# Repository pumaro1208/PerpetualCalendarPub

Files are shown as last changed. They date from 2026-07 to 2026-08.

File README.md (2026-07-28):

# v1.6 PATCH — architecture A' (cam-gated slider strikers + E1 receivers)
Authorized by Ron 2026-07-09. Sim b40 is the functional spec of record.

## Parts (print all in PLA Matte Charcoal — rotating)
- 30_drive_v16 — drive wheel re-head: body + long tooth + hub/crank + THREE
  radial slider channels at 15/30/45 deg (rails z4.0-8.0, lips 7.1-8.0,
  floor pads 4.0-5.2, detent bumps at both seats). Witness dot = 23h channel.
- 31_sliders_v16 — three sliders on one plate. ID dots: 3=23h, 2=22h, 1=21h.
  DISTINCT NOSE LENGTHS: each slider reaches only its own cam track —
  cross-assembly is physically impossible. Strike pin r1.6, band 5.2-8.0.
- 32_camring_v16 — board-top ring (z 4.05-4.75, OD 41.6): three blind groove
  tracks at world r 34.6/37.4/40.2 (23h/22h/21h), lobes (1.6 mm inward) at
  board positions 30/29/28, dwell 1.35 pitch, cosine ramps. Witness dot =
  pos-1 at the OD. Mount: seat on board top, clock the dot to the mesh line
  with the board at Jan 1 (pos 1); thin CA at three points. Registration
  tolerance +/-3 deg (harness G4) — witness clocking suffices.
- 33_receiver_month_v16 — month satellite lamina: mesh profile + spacer hub +
  FIVE E1 involute strike teeth (patent claim 5 form) at 30-deg stations,
  base 6 deg. Witness dot marks station k=0.
- 34_receiver_feb_v16 — single-tooth E1 lamina, same construction.
- 35_leap_shuttle_v16 — the v1.5 leap shuttle re-headed with the E1 tooth;
  the Geneva year key is unchanged (follower pin preserved).

## The cam law (normative, sim-derived)
Striker extended ONLY on its strike evening. Lobe map (400-yr engine sweep):
21h->pos 28, 22h->pos 29, 23h->pos 30 — one lobe per track; the cascade
itself walks the board through the positions, arming each striker in turn.
Stroke 1.6 mm; retracted adjacency clearance 2.54 mm emitted (harness 1.23).

## Acceptance (all 19 gates PASS; all 6 parts watertight, 0 open edges)
Fit: channel gap 5.4 / slider 5.0; lip retention 0.5/side; peg d2.4 in
groove 2.7 (0.35 mm wall engagement). Register: extended pin = FINGER_R
30.70 exact, peg valley/lobe = track radii exact, lobes verified at the pos
lattice and flat elsewhere. Keep-outs: ring OD 41.6 vs pin sweep 42.8;
nose-over-ring 0.45 mm; strike bands identical by construction (5.2-8.0).
Harness lineage: stroke, E1 profile, and station base are the EXACT
parameters judged in arch_a_prime.py (G1 1.13P/1.33P bidirectional, G2
silent, G3 1.23 mm, G4 +/-3 deg) — the emitted parts and the judged
mechanism share one parameter set.

## Bench items on first assembly (Stage 1.5)
1. Slider slide-fit after printing (scrape lips if needed; PTFE dry lube).
2. Detent click at both seats; peg engagement depth 0.35 (verify no lift-out).
3. The characterized 23:15 tight passage: midnight finger entry clearance
   against the mid-push board (from the sim's grind log).
4. Reverse un-skips: park -> pickup -> push, per sim b40.

## Receiver clocking table (harness-judged, 2026-07-09)
Each lamina's witness dot clocks to its satellite per this table. The base
window is the selectivity margin; center it.
| train | satellite | station (carrier) | judged base | passing window |
|---|---|---|---|---|
| month 23h| 210 | STN_M (reference) | 180.0 deg | (session 3) |
| feb 22h  | 211 | STN_M + 1 pitch | 315.0 deg | 310.0-320.0 |
| leap 21h | 212 | STN_M + 2 pitches | 335.0 deg | 327.5-340.0 |
The station offsets are the natural carrier positions of satellites 211/212
(one and two cascade steps ahead of 210) — the harness confirms the
assignment; no new posts required.

## Part 36 — friction-set hour ring (roadmap tier 1, added 2026-07-19)
Press-fit indicator ring on the drive hub: three printed flex fingers grip
the hub column at 0.15 mm interference each (the cannon-pinion principle,
in PLA); the pointer flag reads the displayed hour. USE: after any fast
catch-up cranking (the drawer scenario), twist the ring by hand to restore
the true hour — date advanced, displayed time preserved, the outcome of
the UN-32's date position with one part and zero mechanism. Rides z
8.6-11.6, 0.6 mm above the channel tops; only the fingers touch the hub.
BENCH: verify twist friction is firm but hand-turnable; if too tight,
scrape one finger; if loose, a strip of tape on the hub shims it.
STAGE-C NOTE: the true date-ONLY drive (hands stationary while the
calendar advances) is the keyless-works dog clutch — deliberately deferred
to the watch stage per ROADMAP-clock-watch.md.

# FLAG-FREE DETENT SET (findings 97–99 + coupling redesign, 2026-07-28)
The machine's sole index. The daily drive advances the board; this detent settles
it onto each day's position and holds it. Reversibility is preserved (flexure, not
ratchet). All parts PLA (rotating parts black), print FLAT, no supports.
Regenerate the whole set with `parts/emit_final.py`; gate is `qc_sweep_central.py`.

## Parts
- 02e_board_bigbore — the v1.3 program board (31 involute rim teeth, tip 41.86;
  31 day-tick bumps at r33.5 with the tall pos-1 witness; month satellite post +
  D-key), UNCHANGED except the central bore opened 8.7 → 10.9 mm to take the star's
  press-tube. Prints teeth-up, flat on the bed. THE ONE PART RE-PRINTED from the
  bench (bigger bore is the only change).
- 50d_star_hub — detent star, flag-free. 31 symmetric shallow-triangle notches
  (root 26, tip 28.5 → 2.5 mm deep) on a scallop disc, plus an integral CENTRAL
  press-tube (ID rides the program post, OD press-fits the board bore) that couples
  the star rigidly and concentrically to the board — no outrigger, no drop-in pin.
  Prints scallop-down, tube rising. Rides the post; board seats on the disc top;
  the disc spins on the fixture thrust pad.
- 49_fixture_r58 — basin bench fixture: program + drive posts (square-key sun seat),
  drive collar, a central THRUST PAD the star disc spins on (replaces the program
  collar), and the two bridge-jumper anchor pins at r30.5. Wedge station = 270°.
- 51_bridge_arm — the bridge jumper (finding #99). A pinned-pinned flexure (span 35
  between the boss inner edges; both pin bores OPEN top-to-bottom, finding 64/93),
  1.05 mm wide, carrying a POINTED wedge at mid-span: a sharp apex reaching r27.0
  (clear jump into each notch) with wide shoulders that bear on BOTH tooth flanks
  (geometry centers it). Loaded identically forward and reverse. Beam pulled in to
  r30.5 so the riser is short (~2.2 mm) — the sideways tooth force has little lever
  arm to twist the wedge. k = 0.62 N/mm; peak 23 MPa (2.2× PLA) at the 1.5 mm stroke.

## Design laws honored
Reversibility — pinned-pinned flexure is symmetric fwd/rev, positive transfer, no
ratchet. Full-depth notch + short pointed wedge = a positive index with a light,
clean jump. Both press fits are interference — no glue. The gate in the repo
(qc_sweep_central.py) is the gate that cleared this plate (finding 96 doctrine).

## Bench items on first assembly
1. Star central tube → board bore: designed interference press; tune on first fit.
2. Bridge pins → anchor bores: interference; bores print open top-to-bottom.
3. Wedge drops into each notch with a clear click and self-centers on both flanks;
   verify no twist as the board sweeps its 31 positions.
4. Star disc spins freely on the thrust pad; board seats flat on the disc top.

## Board 02f — pegless/dotless (engine clearance sweep, 2026-07-28)
02f = 02e with the 31 perimeter day-tick pegs (r33.5) AND the three station witness
dots (r35.05) REMOVED. The engine interference sweep (parts/engine_sweep.py, disc-
about-fixed-pivot model, frame self-checked against the sun↔month mesh) found that
on 02e the tall day-1 peg (+0.8mm) and station dots M/F (+0.2mm) poke up into the
MONTH satellite's mesh lamina (underside z10.4) even with the finding-63 spacer —
the 30 short pegs clear by 0.4mm, but those three do not. 02f leaves zero raised
obstacles on the board face except the intended satellite pivot post; the sweep
reports CLEAR. Involute rim, 10.9 press-bore, and the month post + D-key are
UNCHANGED, so the flag-free detent press-fit (star tube -> board bore) is unaffected.
Sun tower confirmed correctly configured (spans LA/LB/LC, meshes at altitude).
02f SUPERSEDES 02e for the reprint. See docs/engine-clearance-sweep.md.

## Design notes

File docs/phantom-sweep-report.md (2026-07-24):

# Phantom-Pass Sweep — Report (2026-07-08)

Push-classified watershed verification on the real profiles, full year of
board parks. The gating metric is TOOTH-PUSH, not contact: grazes are design
behavior if push < 0.35 pitch (crest 0.5); un-gated ADVANCE is failure.
Tooling: phantom_sweep2.py (+ phantom_sweep.py first pass).

## P1 — PASS: month gating works; watershed confirmed on real geometry
Over a full year the 23h tooth vs the 5-tooth month lamina (OFF=9.75)
produces engagement ONLY at the strike passes; all other passes are clean or
graze with worst push 0.042 pitch — an order of magnitude under the crest.
Zero danger-band events. The paired same-pass "strikes" (az -6 @ 1.04P and
az +6 @ 0.75P) are an enumeration artifact: a skip evening advances the board
TWICE (skip + midnight), so the running machine visits only ONE evening of
each pair — WHICH one is selected by assembly date-clocking. Note the az -6
evening's push is 1.04 pitch = TOOTH-COMPLETED (see S4 note below).

## P2 — OPEN: feb single-tooth fires twice a year in the raw scan
The feb tooth's presentation phase advances 210 deg per monthly pass, cycling
all twelve 30-deg phases annually; the raw scan shows 2 crest-crossing
engagements/yr (0.98P and 0.73P on different passes). Whether the running
machine actually VISITS both depends on the skip-inclusive kinematic
sequence and the chosen engagement parity — the same subtlety as P1's pairs,
but across passes. Needs the sequence-aware sweep (enumerate the true
calendar sequence of parks, not all parks) before declaring pass/fail.
Leap shares the single-tooth phase-cycle exposure; same follow-up.

## P3 — leap slider: one critical margin, one healthy spec
ARMED: push 0.507 pitch — 0.007 pitch (0.08 deg) past the crest. RAZOR-THIN:
FDM noise flips it and leap years silently fail to skip. This is the
sharpest margin in the machine and needs geometry attention in the S4/leap
session (deeper armed reach or wider tooth land).
RETRACTED clearance vs cam travel: 1.0 mm -> 0.060 mm (too thin);
1.2 -> 0.255; 1.6 -> 0.654 (the v1.5 follower stroke: HEALTHY, PASS);
2.0 -> 1.052. Minimum viable travel ~1.15 mm; the 1.6 mm design has ~4x
margin. The retracted-gating half of the leap watershed is confirmed.

## S4 note — resolution path upgraded
P1 found an evening whose month-skip push is 1.04 pitch: the tooth itself
completes the pitch, satisfying the bidirectionality rule from the strike
sweep. If that (evening, clocking) combination also reverses — plausible,
untested due to a board-angle/satellite-spin aliasing my quick probes hit —
then S4 is resolved by ASSEMBLY CLOCKING alone, no geometry change: the
date-clocking must place skips on the az -6 evenings and the satellite OFF
must match. The S4 design session should START with this sequence-aware
clocking search before considering the twin-flank receiver.

## Standing next steps
1. Sequence-aware sweep (calendar-true park sequence): settles P2's feb
   double-fire and executes the S4 clocking search at the exact strike
   angles. Highest priority; reuses all of this tooling.
2. Leap armed-margin geometry (with S4 session).
3. Sun-mesh orbit sweep (7t pinion undercut, continuous mesh) thereafter.

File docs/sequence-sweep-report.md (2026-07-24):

# Sequence-Aware Sweep — Report (2026-07-08)

Walks the engine's TRUE calendar sequence of board parks (skips included) and
evaluates every 23h/22h drive-tooth pass at the exact board angle and
satellite spin the machine will occupy. Tooling: sequence_sweep.py; the
calendar walker + per-pass push classification are the standing acceptance
harness for the skip-transfer redesign.

## Headline: NO clocking window exists for the month or feb laminas
Scanned 61 month clockings and 241 feb clockings against the full
calendar-true year. None produces the required pattern (every logical strike
engages >= 0.5 pitch; every other visited pass gated < 0.35 pitch).

The autopsy at the best candidate clocking (month, OFF = 9.75) shows WHY —
both failure classes coexist:
 - FALSE STRIKES: the eve-of-skip evenings (satellite az -5.8) engage at
   1.042 pitch on several months (n = 121, 214, 276, 338) plus stray az +5.8
   engagements on non-skip months (n = 215, 370). Each is a full extra step:
   the calendar runs FAST.
 - MISSED STRIKES: two of the five logical skip evenings get no engagement
   (n = 184) or a 0.042-pitch graze (n = 339): the calendar runs SLOW.
No clocking trades these off to zero simultaneously. Verdict supersedes the
phantom sweep's all-parks PASS (which averaged over parks the sequence never
visits and missed the visited-sequence correlations).

## Finding S7 — the skip gating as built cannot serve the calendar
The presentation-phase engagement window of the current lamina tooth form is
WIDER than one station on the approach side (hence eve-of-skip false strikes)
while the nominal-side engagement varies 0.75 -> 0.04 -> 0 pitch across
evenings the 30-deg station-lattice theory says are equivalent — the physical
engagement depends on approach geometry in a way the lattice doesn't capture.
(The lattice discrepancy itself is an open analysis item for the session; the
empirical verdict does not depend on resolving it.)

## S4 status: clocking resolution is DEAD; redesign confirmed
The hoped-for fix-by-witness-marks is closed. The skip-transfer design
session is confirmed necessary, now with the full requirement set measured:
 R1 bidirectional: tooth-completed push >= 1.0 pitch both directions
 R2 selective: presentation window narrower than one evening's phase step
    (no eve-of-skip engagement)
 R3 reliable: >= 0.65-pitch push margin at every legitimate strike (the
    leap's current 0.507 shows what 0.007 margin looks like)
 R4 gated: all other visited passes < 0.35-pitch push
The twin-flank slot receiver remains the lead candidate: a slot is engaged
positively in both directions (R1), only when entered (R2), and its
engagement depth is designable (R3). Every candidate gets judged by
sequence_sweep.py before any STL is cut.

## Stage 1 print decision (updated)
Hold: sun tower, all three satellites, leap sliding tooth (the skip train —
S4/S7 redesign scope). Clear to print: everything else in the engine — base,
board, drive wheel, jumper, carriers, caps — the daily drive is fully
verified (S1/S2), and the S3 margins are bench items on exactly these parts.
Printing the cleared set banks bearing/detent/double-step data that feeds
the redesign.

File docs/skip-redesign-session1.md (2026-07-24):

# Skip-Transfer Redesign — Session 1 Findings (2026-07-08)

## Candidate tested: pin-and-slot (drive strike teeth -> pins; lamina teeth
## -> twin-rail slots), judged in the calendar-true sequence harness.

R1 SOLVED by the candidate: strike pushes 1.2-1.6 pitch, tooth-completed,
with reverse engagement available by the same slot geometry — the Geneva
pattern delivers bidirectionality exactly as predicted.

R2 UNSOLVABLE by ANY satellite-borne receiver — the decisive measurement:
the satellite's presentation POINTING phase advances only 6.8 deg per
evening (18.39 deg spin minus 11.61 deg orbit). Any physical receiving
feature at r~18 subtends 10-15 deg, so it inevitably presents across 2-4
consecutive evenings. The sequence autopsy confirms: eve-of-skip false
engagements (1.6-2.3 pitch — worse than the tooth, since a rail drives
harder than a crowned tooth corner) at EVERY clocking, plus one strike
evening served a day early. This also retro-explains S7: the original
crowned tooth was a partial-selectivity compromise that failed both ways.

## The architectural conclusion
Skip gating needs a SECOND key whose phase moves a full station per evening.
The machine already owns one: the BOARD advances 11.61 deg per evening.

PROPOSAL for Session 2 — board-position masking:
A thin MASK lamina riding the board at each strike band (or one ring serving
all three), carrying a single APERTURE at the pos-30 (pos-29/28 for feb/
leap) angular station. The drive pin physically reaches the satellite slot
only THROUGH the aperture: on any other evening the mask blanks the pin at
full board-pitch discrimination (11.6 deg/evening — crisp), while the
satellite slot provides WHICH-month gating exactly as the presence concept
intends. Two keys, two questions: the mask answers "is tonight a skip
night?", the satellite answers "is this a skip month?". Both must say yes.
Design notes: masks ride the board (rotation parity preserved — nested,
no inversion); apertures are passive (no springs, no stored state — state
read at moment of use); pin length/z unchanged; adds 1-3 thin laminae to
the board stack and ~1.5 mm of z per band to thread the pin through.
Leap keeps the v1.5 slider (retract spec verified: 1.6 mm stroke, 0.65 mm
clearance) — the slider now retracts the SLOT, and the armed-margin problem
dissolves because the pin-slot push is 1.2P+, not 0.507P.

## Session 2 agenda
1. Parametrize mask ring + aperture + pin z-threading; extend the harness's
   overlap model with the mask (one more polar profile per band).
2. Judge in the sequence harness: all four R's, forward AND reverse, all
   three satellites, plus mask-edge graze checks (the new phantom class).
3. If green: v1.6 patch — regenerate drive wheel (pins), satellites (slots),
   board (+mask laminae), sun tower (band heights); full pipeline;
   witness-mark spec for satellite clocking.
Stage 1 split unchanged: skip train on hold; the rest of the engine prints.

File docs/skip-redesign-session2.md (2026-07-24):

# Skip-Transfer Redesign — Session 2 (2026-07-08)

## E1 verdict: bidirectional YES, selective NO — adopted as the RECEIVER
## FORM, rejected as the complete architecture.

The patent-literal involute receiver (board-tooth profile, superposition-
registered) measured 1.13P forward / 1.33P reverse, settling exactly +-1.000
pitch — R1 solved, party-trick class, 0.37P crest margin. But the calendar-
true selectivity gate fails at ALL 12 station assignments: the day-after
evening engages at 0.77 pitch (over the 0.5 crest -> false strike). The
6.8 deg/evening pointing crawl defeats every receiver form — wedge, slot,
involute — confirming Session 1's structural conclusion with the best
possible receiver.

## Mask analysis: the naive shield is geometrically impossible
Worked through in this session; recording so it stays dead:
 - Any board-riding shield inside the striker's swept annulus (r 40.7-44.9)
   is TOUCHED BY THE STRIKER on masked evenings; a striker pressing any
   board-borne surface IS a false step. Masking the striker's path is
   self-defeating.
 - A shield inside r 40.7 (striker-safe) instead COLLIDES with the emerged
   rigid receiver (tip 41.86) on masked evenings. Rigid receivers cannot be
   masked without crashing into the mask.
Conclusion: the second key cannot be a passive wall anywhere in the
engagement annulus. It must act on a COMPLIANT receiver.

## The converged architecture — generalize the leap slider
The machine already contains the answer, proven twice over: the patent's
sliding plate 212 (springless, cam-positioned, board-guided) and our own
v1.5 live-read follower/slider for the leap. Proposal:

  ALL THREE skip receivers become SLIDING involute teeth (E1 profile) on
  their satellites, positioned by board-referenced cams — radially OUT
  (engageable) only when both keys agree:
    key 1 (which month): satellite spin aligns the slider's cam follower
      with the cam's admission window — the presence concept, now acting on
      a 1.6 mm radial stroke instead of raw tooth exposure;
    key 2 (which evening): the cam profile is indexed to the BOARD lattice
      (11.6 deg/evening discrimination — the crisp key), so the slider pops
      out only at the strike park and is positively retracted the evening
      before and after.
  Retracted clearance is a solved spec (1.6 mm stroke -> 0.65 mm, phantom
  sweep P3). Engaged, the slider presents the E1 involute tooth -> 1.1-1.3P
  bidirectional push. Springless, no stored state (cam read at moment of
  use), rotation-parity preserved. Cost: two more sliders + cam surfaces —
  the leap train's pattern replicated for month and feb.

## Decision for Ron
 (A) Three-slider architecture above (lead candidate: every element already
     exists somewhere in the machine; z-stack grows by the cam surfaces).
 (B) Embodiment-2-style blocked output (larger architectural change; strongest
     prior art for positive indexing; would touch the daily drive too).
Ron's Fig. 2/3 + Fig. 4-9 read now directly informs A vs B — the sliding
plate's stud guidance (Fig. 3) is the template for A's sliders.
Session 3: parametrize the chosen architecture; judge in the sequence
harness (all three satellites, both directions, mask-edge/cam-edge grazes);
if green -> v1.6 patch.

Stage 1 unchanged: skip train held; the rest of the engine prints.

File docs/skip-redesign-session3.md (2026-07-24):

# Skip-Transfer Redesign — Session 3 VERDICT (2026-07-08)

## Architecture A' — cam-gated SLIDER STRIKERS + rigid E1 receivers: PASSES

The inversion that made it buildable: gate the STRIKERS, not the receivers.
The three skip strike teeth on the 24h wheel become radial sliders (three
sliders total, all on one part), extended only when their peg reads a lobe
on a board-riding cam ring. Strike load is tangential, slider travel is
radial — orthogonal, so drive force cannot back-drive the gate (the leap
slider's own proof). Cam contact is a smooth track — no false-step torque
(the v1.5 follower's own proof). Receivers are rigid involute laminae in
the E1 patent-claim-5 form. Two keys: the board-riding cam answers "is
tonight the skip evening?" at 11.6 deg/evening; the satellite station set
answers "is this a skip month?" at 150 deg/month. Both passive, springless,
read at moment of use.

## Sequence-harness judgment, month train (the decisive case), base 6:
  G1  all 5 skip evenings: forward push >= 1.125 P, reverse >= 1.327 P,
      settled EXACTLY +/-1.000 pitch — BIDIRECTIONAL skips in the
      calendar-true sequence. The party trick, end to end.
  G2  non-skip months' extended evenings: 0.000 P — perfectly silent.
      The 5-consecutive-station set lands the 5 skip months exactly
      (stations walk +5/month, 5 and 12 coprime; verified in-scan).
  G3  adjacent evenings, striker retracted at the leap-proven 1.6 mm
      stroke: minimum clearance 1.23 mm (gate 0.30). At 2.0 mm: 1.60 mm.
      (First run reported -0.13 mm from a sign error in the retraction
      model — the harness extended instead of retracting; fixed, re-run.)
  G4  registration tolerance: passes at least +/-3 deg of satellite
      clocking error — assembly-friendly; witness marks suffice.

## Requirement scorecard (R1-R4 from the strike/phantom/sequence sweeps)
  R1 bidirectional tooth-completed push  ....... PASS (1.13/1.33 P)
  R2 evening selectivity ....................... PASS (cam gate, G2+G3)
  R3 healthy margins ........................... PASS (0.37P crest margin;
                                                  1.23 mm retract clear)
  R4 all other visited passes gated ............ PASS (zero contact)

## Remaining before v1.6 geometry
  1. Feb and leap trains through the same harness (single-station cases,
     geometry class identical; leap keeps the v1.5 follower for the year
     key, its striker gains the 21h slider like the others).
  2. Natural-evening re-clocking note: skips land at pos 27/28/29 with the
     serving satellite at -5.83 deg — display mapping shifts one pitch;
     witness-mark spec at base-6 registration.
  3. v1.6 patch: drive wheel (3 slider strikers + pegs + detent bumps),
     board cam ring (3 lobes/tracks), satellite laminae (E1 involute
     receivers), leap slider re-headed, witness marks. Full pipeline:
     regenerate -> watertight -> acceptance sims -> sequence harness ->
     package. Awaiting Ron's approval of A' and his Fig. 3 read on the
     patent's stud-guidance pattern for the slider details.

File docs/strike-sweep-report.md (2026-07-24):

# Strike-Transit Sweep — Physical Acceptance Report (2026-07-08)

Quasi-static 1-DOF contact simulation of the strike transfers using the ACTUAL
generator profiles (31t stub involute board, 24t-basis stub drive tooth at the
+2.0 mm spread center distance, v1.3 strike lamina with symmetric crown, and
the real v1.2 jumper V-nose geometry, detent-coupled). Tooling:
strike_transit_sweep.py + lamina_bidir scans; results in sweep_results.json.

## S1 — CLEARED: the jumper's inherited clocking is correct
Solved from geometry, no assumptions: the V-nose's deepest seat parks the
board with a tooth VALLEY centered on the mesh line to 0.025 deg. The v1.2
jumper at 12 x PITCH is correctly clocked for the v1.3 drive. Detent snap is
strong (seat-vs-crest depth asymmetry ~270:1). Park-error tolerance window
for a clean transit: -1.0 .. +4.0 deg. The pre-print worry is retired;
the bench check remains (verify the printed park phase lands in-window).

## S2 — PASS: the daily (midnight) transfer is fully bidirectional
Forward: settled advance exactly 1.0011 pitch (solver resolution). Reverse:
exactly 1.0000 pitch back. Measured physical backlash: the board holds
through 24.3 deg of reverse crank (~1.6 h of crank time) before the reverse
push begins — this is the documented expectation for the reverse-cranking
bench test, not a defect. Bidirectionality of the daily drive comes from
MULTI-TOOTH interaction: the drive tooth itself carries the board 1.41
pitches (catching the next board tooth), so the tooth — not the detent —
completes the pitch in both directions.

## S3 — MARGIN FLAGS on the daily transfer (bench-first, geometry-second)
(a) Forward excursion reaches 1.412 pitch: only 1.02 deg (~0.75 mm of flank
position) short of the next detent crest. Past it = DOUBLE-STEP (skips a
day). (b) Nominal entry approach clearance is 0.021 mm — a graze. Both sit
inside typical FDM error. Plan: measure on the Stage 1 print first (count
double-steps over a simulated month of cranking; listen for entry clicks);
if real, the fixes are small (drive-tooth tip relief, +0.3 spread) and cheap
to regenerate. Not a print blocker by itself.

## S4 — DESIGN FLAW: all satellite strikes are FORWARD-ONLY as built
The month lamina's tooth-only push is 0.753 pitch; the JUMPER completes the
remaining 0.247. That completion is irreversible: reversing, the descending
drive tooth arrives to find the lamina a quarter-pitch beyond reach and
passes through empty space. Verified exhaustively: no satellite clocking
(121 scanned, mod 30), at either candidate strike evening (satellite at
-5.83 or +5.78 deg), with lamina reach extended up to +1.3 mm, produces a
reverse-capable transit. The feb and leap laminas share the single-tooth
geometry class: the same result applies to the 22h and 21h strikes.

Consequence: reverse-cranking through any month-end cannot un-do the skip.
The board un-steps daily but the skips stand — the calendar de-syncs. This
violates design law 1 (full bidirectionality), which the simulator's engine
assumes ("reversing: month skip undone" is real in the spec, unimplementable
in the current laminas).

THE RULE THIS EXPOSES (add to the design laws' commentary): a strike
transfer is bidirectional only if the TOOTH ITSELF pushes >= 1.0 pitch; any
completion delegated to the detent is a one-way ratchet in disguise. The
board drive satisfies it via multi-tooth contact; a single-tooth lamina
cannot (single-flank contact arc maxes near 0.75 pitch at this geometry).

Fix directions for the design session (transfer must be PROVEN before
geometry, per project protocol):
  1. Asymmetric lamina tooth: extend the reverse flank so the descending
     tooth catches it despite the detent's completion (~5-7 deg wider on one
     side); requires phantom-pass clearance checks on adjacent evenings.
  2. Twin-flank receiver: two short teeth per station forming a slot the
     drive tooth enters — contact on either flank by direction (Geneva-like,
     positive both ways).
  3. Reduce detent completion authority for skip strikes (deeper conjugate
     engagement via module/center-distance changes at the strike bands).
Option 2 is the one that satisfies the >= 1-pitch-push rule by construction.

## S5 — Satellite assembly clocking
Forward-capable clocking exists in a window around OFF ~ 9-10 deg (mod 30);
the exact witness-mark spec should be issued together with the S4 redesign
(the fix will move it). The clocking failure mode (satellite meshed one
sun-tooth off = 30 deg = silent month-end miss) stands confirmed; witness
marks on all three satellites are required in the next patch regardless.

## S6 — Housekeeping
strike_profile's docstring claims "+theta corner relief"; the code implements
a symmetric crown. Docstring stale; code is the better design. Correct the
comment in the next patch.

## Stage 1 impact
S1/S2 clear the engine's daily drive for print. S3 is bench-first. S4 means
the satellite laminas (sun tower strike bands + leap tooth) as generated are
forward-only: printing Stage 1 now yields a demonstrator whose skips work
forward and cannot be reverse-cranked through month-ends. Options: hold the
sun-tower/leap parts for the S4 session, or print the full Stage 1 as a
forward-alpha to bank assembly/bearing/detent learning while S4 is designed.
Ron's call.

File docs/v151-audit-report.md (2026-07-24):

# v1.5.1 — Audit Pass & Patch Report (2026-07-07)

Full-solids audit of the v1.5 set against the simulator spec and design laws.
**Eight findings.** Six fixed and gate-verified in this patch; one converted to
a documented manual-alpha pending a design session; one flagged OPEN as a
design session. All 31 parts regenerate watertight; the simulator's Gregorian
logic re-passes all acceptance points headlessly (Feb 2100=28, 2104=29,
2400=29, plus 1900/2000/2027/2028/2096/2200/2300).

## Fixed in this patch (regenerated: 01, 07, 11_cap_main, 17, 23, 24, 25, 26, 28)

**F1 — Weekday drive pin vs east bridge post (severe).** The pin's daily orbit
(r23.5 about the drive axis) passed 2.31 mm from the east post axis — through
the post. Post moved (60,−22)→(60,−34); the orbit's max |y| is 23.5, so y=−34
is unreachable (clearance now 13.1 mm). Base gains a support lobe (the new
position fell off the old outline); the bridge reaches the boss by a south
tab. Second-order find: the bridge's continuous top rail crossed the orbit at
abs x 56.4–58.3 — it now terminates at abs x 54.25 (local 84.0). Gate-checked
against post, boss, tab, and rail, including the pin's cone base.

**F3 — Annual Geneva could not complete an engagement (severe).** Textbook
4-slot (C=43.55, R=30.8=C·sin45) requires slot length 2R−C = 18.05 mm; the
ears provided 5.2, and at mid-engagement the pin (dipping to r12.75 from ring
center) collided with the solid spoke, the riser columns, the century ring,
and the cam band; the r1.9 pin root could not enter the 2.6 slot; the arm
swept into the spokes. **Rebuilt:** the receiver is now a hub on a coaxial
TUBE integral with the programmer; four twin-rail spokes carry a continuous
2.6 mm slot from r11.4 to the rim (22.0 mm), raised jaws at the mouths, and a
stiffening hoop above the pin's top. Arm 1.4 mm thick in its own band; only
the pin rises into the slot band; root confined to the arm band. A 721-step
engagement sweep passes with ≥0.25 mm lateral, ≥0.30 mm floor, and ≥5.3 mm
tube clearance. NOTE (first attempt, for the record): outboard riser columns
were tried and REJECTED — any column linking ring body to rails crosses the
century ring's swept annulus. The tube is the correct topology.

**F4 — Annual shaft could not seat.** Bore was 1.5 deep on a 4.2 stud; now
bored to 4.4.

**F5 — Gregorian z-stack had no valid datum.** The platform can only seat on
the sun-tower top (z 29.0); the v1.5 constants assumed 1.4 mm lower. The
whole layer is now TOP-relative and the band table closes with explicit
margins: ring 30.6–32.4 (cam 31.4–32.4) / lobes 32.6–33.6 / century body
33.6–34.6 (features to 35.2) / arm 35.6–37.0 / rails 37.4–39.0 / jaws→40.4 /
pin→40.0 / hoop 40.4–41.6. Century lobes moved to their OWN band below the
body (they previously interpenetrated the cam's long-face material); the
follower foot (post now to 33.3) spans cam + lobe bands and reads the max, as
the superimposed-cam concept intends. Base post spigot extends to 39.0; new
cap_main (r6.8) retains the stack above the rails hub.

**F6 — Bridge bosses had no bores.** Solid cylinders; now bored r3.35.

**F7 — Idler 2 installs inverted, silently.** The chain's z-bands connect only
with I2 flipped (I1 pegs 5.5–7.3 → flipped I2 disc 5.8–7.3; I2 pegs 4.0–5.8 →
shaft star 4.0–5.5). Idlers now carry a TOP witness dot on the peg face.
ASSEMBLY: I1 dot UP, I2 dot DOWN. New clocking dots also on the programmer's
slot-0 jaw and the shaft arm (standard Geneva entry clocking: align at park).

**Housekeeping.** v1.5 docstrings described the abandoned leap-pin/Oldham
drive and a shaft stud at (14,−44) (actual (10.35,−42.3)); dead code in the
shaft part; bridge hub docstring said 41.65 vs code 43.15. Corrected in the
patch generator; superseded text remains only in the legacy files.

## F2 — Century auto-advance: geometrically impossible as designed (decision made, session owed)

The programmer's takeoff pin and the century ring are COAXIAL. A pin fixed to
one coaxial ring sweeps one circle forever — no radial approach or retreat —
so it cannot index the other ring, for exactly the reason the satellite-pin
annual drive was abandoned (see v1.5 README). As drawn it was worse: the pin
sat inside the century's material (could not assemble), the century's r8.4
bore floated 4.6 mm over its r3.8 sleeve, and the 100 notches at r8.4 had
0.53 mm pitch vs 1.1 mm notch cuts — geometrically degenerate.

**Patch decision: MANUAL-SET ALPHA.** The century ring now rides the
programmer tube (bore 6.55 on OD 6.4 — the proven ring-on-ring pattern), is
friction-held by the raised platform leaf, and carries 100 station ticks, the
labels 24/21/22/23 at stations 0/25/50/75, and OD grip knurls. Lobes and
their read function are UNCHANGED — Feb 2100/2200/2300 still read 28 days;
only the once-per-4-years advance is by hand (precedent: year-ring friction
indexing, open item 3). "State read at moment of use" is preserved; nothing
is stored.

**Design-session proposal (recursed counter):** split the 100-station counter
the way the calendar itself recurses — a 25-station quarter-century ring
(printable 4.3 mm pitch) plus a 4-station cycle ring carrying the three
lobes — with offset transfer wheels on platform studs breaking the coaxial
impossibility. The stepped (not continuous) motion of the programmer means
the transfers must be indexing (Geneva-class), not lantern chains. Needs its
own sim verification before any STL.

## F8 — OPEN: display bay is systemically over-committed (design session)

Two independent problems, verified numerically, NOT patched here:

1. **Vertical budget.** Bay is 4.0 tall (z 4–8); the pin plate takes 6.4–8.0.
   Every raised wheel feature interferes: text 0.2 into the plate, carry
   fingers 0.7, tens pegs 1.1, year-units pegs 1.4 — and the month star's
   underside annual pin is 1.7 mm INSIDE the base plate, so the annual chain's
   first link never engages (the Geneva above is verified but currently has
   no working input).
2. **Rotating pin-ring keep-out.** The pin plate rotates daily with the board;
   its 31 pins sweep the FULL annulus r26.7–32.1 (from origin) at z 4.1 up to
   the plate. The month star band/finger, the year stack body/pegs, and the
   date band/tens pegs all cross that annulus above pin-bottom height —
   daily collisions. The bridge deck also cannot cross the plate's footprint
   at any legal z as drawn.

The bay needs a re-layout session with two hard rules: a stated vertical
budget (raise LIFT; pins lengthen to match) and a keep-out discipline — only
intended lantern-mesh material inside r26.7–32.1. Wheel positions, the pin
plate footprint, and bridge deck z all move together; this is v1.4.1's scope
revisited, not a patch. Until then, Stage 1 (engine) printing is unaffected;
Stage 2 (display) printing should WAIT.

## Verification record
- 31/31 parts watertight (open-boundary check; coincident stacked faces noted
  as benign).
- 30/30 acceptance gates pass (acceptance_v151b.py), including the 721-step
  Geneva engagement sweep.
- Simulator Gregorian logic headless re-verified, 10/10 points.
- Simulator caption "century ring — 1 station / 4 yrs" now overstates the
  hardware (manual-set); one-line edit recommended when the spec file is next
  touched. The sim's calendar behavior itself is unchanged and remains the
  functional spec.
- Inspection sheet: v151-inspection.png (F1 plan, F3 plan, F5 band section).

## Files
- generator_v151.py — the patch generator (runs after v13/v14/v15; overwrites
  01, 07, 11_cap_main, 17, 23, 24, 25, 26, 28).
- acceptance_v151b.py, watertight2.py, simcheck.js — verification suite.
- stl_v13/ — complete regenerated 31-part set + display_multicolor.3mf.

## Addendum (post-release): simulator drawing fixes — flaw #16
Ron's inspection caught the 23h purple hour finger missing the purple month
tooth cluster. Confirmed numerically: pre-existing v1.3.1 drawing bug — the
self-clocking IIFE calibrated OFF_M and OFF_F **mod 30** (any tooth station)
instead of **mod 360** (the stations that physically carry teeth: month lamina
has 5 of 12). Misses of 17.6–30.4 mm at every month strike. The ENGINE was
never affected (strikes fire from state logic), so all functional
verifications stand. Fixed: mod-360 calibration; verified 1.12 mm tip-to-tip
contact at six consecutive month strikes (station sequence 0→10→8→11→9→0
closes exactly), plus feb (22h) and leap (21h) strikes. The station set
[0,8,9,10,11] was proven correct as drawn. Also fixed in the same pass: a
replace-all regression from the easing edit had applied the Geneva-receiver
angle formula to the cam-faces block with the wrong face indexing; faces now
index q against the eased angle as ang0−q·90 (face==st.face at the read
marker when parked; +90/yr presents the next face). Full regression suite
re-passes: easing continuity, pin-slot 0.01°, 2027→2100 drive, Feb-2100
cascade forward/reverse.

## Drawn-contact acceptance gates (new standing tool: sim_contact_gates.js)
The simulator's drawing layer now has its own gate suite, run over a full
400-year Gregorian cycle (146,097 days). Usage: `node sim_contact_gates.js
[simulator.html]`; exits nonzero on any failure. Results for the current spec:
- month (23h): 2000/2000 strikes, tooth contact 1.12 mm exactly
- feb (22h): 400/400 strikes, 1.12 mm
- leap (21h): 303 armed strikes at 1.12 mm + 97 retracted passes — the
  Gregorian census (303 common + 97 leap years per 400) drops out of the scan
- daily (24h): finger centered in the board valley (miss < 1.5 deg), radial
  penetration 1.12 mm, sampled 1506 midnights
- Geneva receiver: pin-slot worst miss 0.006 deg across all 400 engagements
- cam faces: drawn face at the read marker matches st.face at every parked day
Gate note: the daily transfer is a valley/flank engagement, not a tip strike —
the gate measures valley centering + penetration, unlike the satellite gates
which measure tip-to-tip. Standing rule adopted: any future simulator drawing
change re-runs this suite alongside the headless logic checks.

## Addendum 2: flank-push drawing kinematics — flaw #17 (found by Ron)
The green midnight finger visibly plowed through the board's leading tooth for
~40 minutes before each strike: the finger's tip enters the board's tooth
annulus 45 min before the hour, but the engine quantized the step to the hour
and eased AFTER it. Physically that early contact IS the drive. Fixed by
rewriting phiDeg as a pure function of (state, time) drawing the true
flank-push. Ron's second catch on the same feature corrected the contact
DIRECTION: the rising finger FREE-CROSSES the open gap first (entering with
0.56 deg / 0.40 mm clearance over the trailing tooth -- the geometry's only
slack), picks up the LEADING flank ~12 min before the hour, and contact-
tracks it one full pitch, releasing exactly at tip-circle exit ~45 min after
the hour. Parking phase -6.08 deg mirrors the physical detent clocking; the
first attempt (-5.53 deg, tracking from entry) made the trailing tooth chase
the finger head-on and is superseded. Verified: worst drawn incursion 0.018 mm, phi continuous
(0.23 deg/min max), forward/reverse drawing identity exact (0.0000 deg) —
bidirectionality now holds in the picture, not just the state. Satellite tooth
anchors recalibrated to the new convention; strike gates read 1.73 mm
tip-to-tip at the hour (finger at 0.756 push phase), all 400-year gates pass.
MECHANISM NOTE for the physical bench list: the daily drive's exit clearance
is only ~0.40 mm equivalent by this geometry — add "midnight finger exit
clearance" to the Stage 1 hardware checks alongside phantom grazes.

## Addendum 3: patent alignment pass (post EP1351104 full-text review)
The simulator now carries the patent's element identities and the session's
design discoveries: header restated as the EP1351104 Fig.2/3 architecture
map (board 204, fixed 7t sun 203, satellites 210/211, leap slider 212 =
the patent's sliding plate, strike teeth 241-243 ahead of the daily long
tooth 208 on the 24h wheel 13); axis and satellite labels renumbered to the
patent numerals; the satellite strike teeth are drawn in the ADOPTED v1.6
receiver form (involute board-tooth profile per patent claim 5 / the E1
measurement: 1.13P fwd / 1.33P rev, party-trick class), replacing the
superseded crowned wedge; the header notes the skip-train v1.6 status
(evening selectivity via cam-gated sliders pending). Tip geometry and all
calibrations unchanged; full gate suites re-run and green (400-year
drawn-contact gates, flank-push/backlash verification). Engine logic
untouched -- the calendar behavior remains the spec.

## Addendum 4: retracted leap tooth drawn retracted (found by Ron)
Reverse-cranking through Feb 29 2028, the 21h finger visibly passed through
the leap tooth's outline: retraction was drawn as a hollow ghost AT FULL
REACH. Fixed: hollow (retracted) strike teeth now draw at the slider's true
retracted radius (v1.5 follower stroke, tip pulled in 1.6 mm -> the finger
clears the drawn tooth by ~0.5 mm, matching the phantom sweep P3 physical
spec). Armed teeth unchanged at full reach; all calibrations and the full
gate suites re-run green. Ron also confirmed the daily (green) engagement
renders perfectly through the reverse leap-Feb cascade -- the flank-push +
backlash model's hardest case, passed by eye.

## Addendum 5: satellite strikes ride their fingers (found by Ron, #19)
The satellite strike engagements drew loose — teeth kissing the finger only
at the anchored hour instant, drifting before and after — because the board's
flank-push profile was applied 1:1 to strikes whose receiving tooth actually
sweeps at 1.2524x the board rate (orbit + 19/12 spin lever over the reach).
Fixed: satellite hours (21/22/23) get their own ratio-true tracking profile
(contact window +-7.27 deg of finger azimuth, board advancing at 1/1.2524 of
the finger; anchor re-set to mid-contact at the hour). Verified: feb-tooth
tip-to-tip holds 0.8-1.1 mm from pickup through release across the whole
push window, then releases; strike gates now read 1.13 mm at the hour —
matching the daily drive's 1.12 mm working depth. All suites green.
Known approximation: satellite reverse uses the same profile (no per-tooth
backlash width modeled) — a small snap on mid-push reversal only.

## Addendum 6: satellite contact drawn at the FLANK, not head-on (Ron, #20)
The ratio-true tracking (addendum 5) anchored the tooth's AXIS on the
finger's AXIS: tips facing tips, 1.1 mm apart, riding in formation — a
head-on butt, which is not how gears touch. Fixed: satellite teeth now
anchor on the DRIVEN-FLANK side, laterally offset by the sum of the two
half-widths (5.06 deg of spin ~ 1.6 mm), direction-aware via renderDir
(forward: the finger's upper edge drives the tooth's lower flank; reverse
mirrors). Strike gates re-derived for the flank geometry: tip-to-tip at the
hour now 1.82 mm (band 1.5-2.4, hypotenuse of 1.12 radial working depth and
the lateral offset); all 400-year gates green. Known approximation: the
offset flips instantaneously on direction reversal (with the backlash snap).
The visual contract now holds machine-wide: every engagement draws as flank
contact — the daily tooth in its valley, satellites at their flanks.

## Addendum 6b: push window re-timed for the flank offset (Ron, #20 part 2)
Moving the tooth to the flank side (addendum 6) changed the geometry without
re-timing the push window: the rising finger reached the relocated flank
~1.6 mm before the board began yielding — a drawn collision on every
satellite approach (caught by Ron on the 22h feb entry). Fixed: the
satellite contact window now runs from where the finger's edge actually
meets the offset flank (beta -5.06) to tip-circle exit (+8.78); anchor
re-derived (frac at the hour 0.366). Verified minute-by-minute through a
full feb window: approach closes 1.85 -> 0.06 mm, edge rides the flank at
0.06-0.23 mm through contact, releases to 1.5 mm — no interpenetration.
Gate band re-derived for the new contact phase (1.33 mm at the hour,
band 1.0-1.7); all 400-year gates green.

## Addendum 7: direction flips traverse, not teleport (Ron, #21)
Reversing then inching forward, the contact pair jumped visibly: the flank-
side offset and the board's contact branch both switched INSTANTLY with
renderDir — a ~3 mm tooth teleport at every direction change. Fixed with an
eased direction (dirSmooth) proportional to CRANKED TIME: a flip now
traverses the backlash over ~9 crank-minutes (0.15 h), blending both the
flank-side offset and the board's contact-branch selection; a day-sized
jump completes the traverse in one call. Fixing it exposed a second issue:
the satellite push window (re-timed in 6b to tip-circle exit) overlapped
the NEXT hour's board contact by ~8 minutes on cascade nights — a drawn
double-drive that lagged the midnight tracking by up to 1.1 deg. The
satellite window now completes at beta +7.60, 2.5 crank-minutes before the
midnight pickup. Verified: edge tracking 0.111 deg worst both directions,
reverse onset 3.80 deg, continuity 0.35 deg/min, all 400-year gates green.

## Addendum 8: TRUE contact — Ron was right, my metric was blind (#24, #25)
Ron reported drawn jams in reverse satellite engagements three times; I
dismissed them twice using an "interpenetration" gate built on minimum
point-pair distance — a quantity that is ALWAYS positive and structurally
incapable of detecting overlap (#24, mine). A true polygon test showed the
drawn silhouettes interpenetrating up to 0.72 mm forward and 1.10 mm in
reverse through every satellite engagement (#25, Ron's). Root cause: the
linear tracking profile + constant lateral anchor hold the pair together
only to ~1 mm against the real wedge shapes.
FIX: a TRUE-CONTACT draw solver (phiDraw): during any live strike window the
board yields, in the drive direction, until the ACTUAL tooth and finger
polygons kiss instead of cross — solved against the COMBINED predicate over
all simultaneously-live pairs (reverse handoffs overlap one pair's contact
tail with the next pair's approach). phiDeg stays pure for the logic layer.
VERIFIED: zero overlapped minutes across full 4.5 h cascades swept
minute-by-minute in BOTH directions; the full_review_audit metric replaced
with the polygon test (P1/P2 all PASS, overlap-minutes 0 everywhere); all
standing suites green. The drawn step during solved contact can reach ~2.3
deg/min (the solver enforcing true geometry against the approximate base) —
the honest motion, not a snap. Ledger: 25 flaws, 21 caught by Ron's eye.

## Addendum 9: JAM DETECTION — the simulator refuses silent pass-through
Per Ron's request, interpenetration is now a first-class detected condition.
The true-contact solver (addendum 8) either separates the engaged
silhouettes or declares a JAM: red banner, HUD message, auto-pause (crank
still live so the user can back out). Two watch classes: strike pairs (the
combined polygon predicate over all live windows) and a board-level foul
watch (midnight finger deep multi-point incursion into the board form —
the mis-park failure mode, threshold 0.6 mm / 3+ points so legitimate
flank riding never trips it).
VERIFIED: negative — 540 minutes of forward+reverse cascades on the correct
machine, zero false alarms; positive — alarm path unit-proven end to end
(fires, messages, auto-pauses) under constricted solver authority.
Engineering note worth keeping: injected clocking errors up to 12 deg GRIND
THROUGH rather than jam (the solver escapes, as the quasi-static physical
sweeps also showed) — hard jams in this mechanism come from the mis-park /
multi-constraint classes the watches now cover, not from satellite clocking.

## Addendum 10: jams now STOP the machine (Ron, #26)
The first jam implementation flagged and painted a banner but returned the
overlapping geometry and let time keep flowing -- the simulator glitched
PAST the very condition it detected (Ron's catch). Rebuilt as a real
unilateral constraint:
 - STICKY CONTACT CORRECTION: the draw correction persists frame to frame
   and rides the contact boundary continuously -- pushed hard by contact,
   relaxed toward the base model at a bounded rate (14 deg per cranked
   hour), stopping exactly at touch. No snaps at engagement or release.
 - TRUE STOP: on an unclearable jam the drawing HOLDS at the last clear
   configuration and advanceHours/reverseHours REFUSE time in the jamming
   direction (direction persisted from detection, so backing out is always
   possible and never re-gated). Banner + auto-pause as before.
VERIFIED: correct machine, full cascades both directions: 0 alarms, 0
overlapped minutes; jam lifecycle proven end to end under constricted
authority -- fires, refuses forward crank exactly (h frozen), backs out,
clears on exit from the window. All standing suites green.

## Addendum 11b (#27 part 2): Ron's first-crank jam — the side alarm's blind spot
Reproduced at frame granularity (0.5 sim-second steps): a false JAM at
23.49 with no pair name — the fingerprint of the bolt-on board-foul watch.
Root cause: the 23h strike's legitimate contact correction shifts the drawn
board ~1.7 deg while the incoming DAILY finger's geometry lived outside the
solver's constraint set; the side alarm compared the corrected board
against the uncorrected finger alignment and tripped. Fix: the daily pair
(finger 208 vs board 204 form) is now a first-class solver constraint near
midnight — the corridor policy balances strike corrections against the
midnight pickup like any other wall — and the bolt-on alarm is retired
(genuine daily fouls flow through the same jam path, named and logged).
VERIFIED: Ron's scenario clean through midnight at 0.5 s frames; forensic
cascade log re-run (fwd 0.035 / rev 0.16 deg per 3 s step, no jams); all
standing suites green.

## Addendum 11c (#27 closed): jam-free and glitch-bounded, both directions
Final state after Ron's first-crank jam report. The daily pair (finger 208
vs board form) is a hard solver constraint near midnight (never steering);
steering is corridor-centering over strike pairs only, clamped to the
physical band (driven contact only ever demands correction in the drive
direction); all constraint resolutions are rate-capped (absorb, not
teleport). VERDICT at true frame granularity (0.5 sim-second steps):
REVERSE max drawn step 0.006 deg (glass); FORWARD max 0.90 deg -- a single
absorb event per cascade at the 23:15 tight passage, where the midnight
finger enters the tip circle while the month push is completing. That
passage is REAL: flagged to the Stage-1 bench list (measure midnight-finger
entry clearance against the mid-push board on printed parts). Zero jams,
zero freezes, Ron's fresh-load scenario clean; genuine-jam path verified
(fires, logs, refuses crank, backs out); audit gate updated to permit the
characterized <=5-minute absorb transient. All standing suites green.

## Addendum 12: two-axis versioning (Ron's process catch)
The simulator carried "v1.5.1" through ~a dozen substantive builds — design
version and simulator build were conflated, making screenshots and jam logs
untraceable to the code that produced them. Scheme going forward:
 - DESIGN version (v1.5.1): increments with physical geometry only.
 - SIM BUILD (b-number): increments with EVERY simulator change; shown in
   the header and the drawn caption, stamped into every jam-log entry.
Current: v1.5.1 / sim b28. Retro mapping: report addenda 1-11c were builds
b16-b27 (numbered to match the flaw ledger). Rule: no sim change ships
without a build bump; the changelog is this report's addenda.

## Addendum 13 (b29): the GRIND state — no silent overlap, ever (Ron, #28)
Ron caught the last silence: the capped absorb resolves overlaps by gliding,
so the drawing showed real interpenetration for ~4 sim-seconds at the 23:15
tight passage with no flag and no log entry. "Resolvable" had been
conflated with "unloggable." Fixed with a third machine state:
  GRIND (amber, logged, non-blocking): the drawn position still overlaps
  while a capped absorb resolves it -- amber strip names the pair, entry
  logged (kind:'grind', build-stamped) to the same panel/console/window.jamLog.
  JAM (red, logged, blocking) remains reserved for unclearable contact.
VERIFIED: full cascade sweep -- exactly one grind episode logged (month
210 vs 23h + daily 208 vs board, fwd, the characterized 23:15 passage),
zero jams, all standing suites green. The simulator now has no state in
which impossible geometry is displayed without acknowledgment.

## Addendum 14 (b30): the masthead was never wired (Ron, #29)
The H1 heading and browser-tab title still read "v1.3" — frozen since the
v1.3 days through two design versions and thirteen builds, and sitting at
the top of every screenshot. The two-axis scheme (addendum 12) had stamped
the subtitle, caption, and logs but missed the most visible strings on the
page. Fixed: the masthead now reads "v1.5.1 engine / v1.6 skip train
pending" with the sim build; the tab title carries both axes. Rule
extended: a version-string audit (grep for stale axes) joins the build-bump
checklist.

## Addendum 15 (b31, #30): pair-2 "in front of the finger" — the architecture fix
Ron's report: notch 1 engages, notch 2's tooth sits AHEAD of its finger
(unpushable), failure surfaces at notch 3. Diagnosis in two layers:
(1) STALE CONSTANTS: the b27 finger slimming changed the tip half-width
    (0.4*hw scales with hw); the flank offset and anchors derived from the
    fat finger were never re-derived. SOFF re-derived: 5.06 -> 3.82 deg
    (sim, gates, audit in lockstep).
(2) ARCHITECTURE: the runtime correction was a GLOBAL scalar -- pair 1's
    +2 deg contact demand displaced pair 2's tooth ahead of ITS finger.
    Fixed by calibration: the per-pair touch-fix curve was MEASURED across
    the window (both directions) and baked into each satellite hour's own
    window term (_CF/_CR + cSat, ramped to zero at branch edges). Per-pair
    corrections cannot displace neighbors; the runtime solver returns to
    hairline-guard duty.
VERDICT: residual touch error 0.25 deg worst (was -2.4); frame-granularity
max drawn step 0.002 deg fwd / 0.043 rev (was 2.2/3.4 at the worst);
zero jams, zero grinds, Ron's scenario clean; strike gates measure 1.53 mm
at the hour -- converging to the daily drive's own working figure without
re-banding. All standing suites green. sim b31.

## Addendum 17 (b33, #32): parked teeth now sit right — the anchor carries the mean
Ron's persistent visual (tooth 2 unpushable, tooth 3 worse) survived b31's
per-pair curves because the curves act ONLY inside each window: between
strikes the PARKED teeth still sat at the raw ~1.7 deg anchor error — which
is exactly what an inspecting eye sees mid-evening. Fixed by moving the
mean error into the ANCHOR itself (IIFE constant -1.4402 -> -3.1402) and
reducing the curves to the residual in-window slope (+-1 deg, zero-mean).
VERIFIED: worst in-window touch residual 0.00 deg across ALL THREE pairs
(measured per pair this time, not extrapolated from one); parked lattice
spacing consistent (29.5 deg between adjacent teeth = the finger pitch);
all suites green (strike gates 1.66 mm at the hour, in band); forensic
cascade fwd 0.47 / rev 0.05 deg per 3 s step, no jams, no grinds. sim b33.
Note for verification: the masthead shows the build — confirm b33 after a
hard refresh before judging.

## Addendum 18 (b35, #33 ROOT CAUSE): console.info killed the machine
Ron's log line delivered the verdict: "console.info is not a function · at
_finish (about:srcdoc:788)". He views the simulator in a sandboxed
about:srcdoc preview whose console object is only PARTIAL. The grind logger
(b29) called console.info -> THREW on the first grind of every cascade ->
pre-b32 that killed the rAF loop permanently: the DISPLAY FROZE at the last
good frame while the engine kept advancing under the crank. Every
"mechanical" mystery since b29 -- teeth in unpushable positions, pushers
glitching, jam-like freezes -- was a STALE FROZEN FRAME being inspected
against a moving engine. The physics fixes along the way (b31 per-pair
curves, b33 anchor) were real improvements to real drawing errors, but the
persistent symptom was this.
FIX (b35): all console calls route through a sandbox-safe shim (_con) that
tolerates any partial or absent console; verified under a FULLY DEAD
console object: cascade clean, jam path fires and logs without throwing;
all standing suites green. Lesson encoded: the runtime environment is part
of the machine; logging must never be able to stop the clock.

## Addendum 19 (b36, #34): Ron rediscovered S7 from the pixels
The persistent visual — a tooth hugging the UNPUSHABLE side of its striker
before its strike — is the drawn truth of physical finding S7: the
satellite presentation crawls 6.8 deg/evening, so on the eve-of-strike pass
the tooth sweeps the wrong flank of its striker at 0.41 mm minimum
(occasionally grazing: the grind entries in Ron's logs are this family).
This is the v1.3-v1.5 skip-train disease, measured in the calendar-true
sequence sweep (false pushes to 1.04P), unclockable by design, and the
reason architecture A' exists: v1.6 retracts the striker through this pass
(1.23 mm clearance, harness-proven). The simulator draws v1.5 because the
v1.6 geometry patch is pending — it was showing the diagnosed disease
honestly, and Ron's eye found it independently.
b36 ANNOTATES the pass on screen: an amber dashed marker with the live
graze distance and the one-line explanation, drawn whenever a satellite
tooth is in its wrong-side adjacency phase. All standing suites green.
The definitive cure remains the v1.6 patch, which awaits Ron's A' sign-off.

## Addendum 20 (b37): ARCHITECTURE A' LIVE IN THE SIMULATOR — Ron's sign-off
With Ron's approval, the v1.6 skip train is implemented in the spec of
record. THE CAM LAW (now normative for the physical cam ring): each skip
striker (21/22/23h) is a radial slider on the 24h wheel, extended by its
board-riding lobe ONLY on its own strike evening -- lobe dwell D in
[-0.60,+0.80] h around the hour with 0.10 h ramps, stroke 1.6 mm; the
daily tooth 208 stays rigid. Drawing, contact solver, and gates all honor
the retraction in lockstep.
VERDICT: the S7 adjacency pass -- the flaw Ron rediscovered from the pixels
-- now clears at 1.02 mm drawn (was a 0.41 mm wrong-side graze; harness
spec 1.23 mm); strike evenings engage exactly (extension 1.00 at the hour,
0 outside); full cascades at frame granularity: 0.002 deg fwd / 0.000 rev,
zero jams, zero grinds; the on-screen badge now shows the CURE (green:
'striker retracted through the S7 pass') instead of the disease. All
standing suites green. sim b37.
NEXT SESSION: the physical v1.6 patch -- drive wheel with 3 slider
strikers + pegs + detent bumps, board cam ring implementing the cam law
above, E1 involute receiver laminae, leap re-head, witness marks; full
pipeline (regenerate -> watertight -> acceptance sims -> sequence harness
including feb/leap -> repackage).

## Addendum 21 (b38, #35): reverse un-skips now PUSH — Ron's daylight catch
On v1.6's first reverse test, Ron saw the extended strikers riding a visible
hairline OFF the teeth through the un-skips — present but not pushing. Root:
the b33 anchor shift was centered on the FORWARD mean and the reverse
residual (+0.15..0.31 deg standoff) was never re-verified — plus the reverse
table predated the A' geometry. Recalibrated on the live b37 build and
folded in: reverse residual now 0.07 deg worst (touching); cascades at frame
granularity 0.002 fwd / 0.000 rev; all suites green. Standing-rule
extension: every anchor or geometry change re-verifies BOTH directions.
Behavior confirmed correct per the design law: in reverse the cam
re-presents its lobe at the same board states, the striker extends, and its
lower edge drives the tooth's upper flank back — bidirectionality by
state-read, exactly as the A' session specified. sim b38.

## Addendum 22 (b39, #36): reverse strikers PUSH, not PULL — the flank-side fix
Ron's sharpest catch yet: reverse un-skips were happening, but the drawn
striker appeared to PULL the tooth — impossible, teeth only push. Measured
on b38: through the reverse un-skips the lead (tooth az - striker az) sat
at +1.43..+1.62 deg — the tooth ABOVE the descending striker, riding the
WRONG (forward) flank: geometric contact, physical tension. Root: every
contact probe and both prior calibrations measured DISTANCE-to-touch but
never the SIDE — the b38 bidirectional scan locked onto the NEAREST
overlap boundary, which is the forward flank, one striker+tooth width
above the correct one.
FIX: the reverse curve was recalibrated seeking the LOWER boundary of the
overlap interval — tooth just below the striker, its upper flank on the
striker's lower edge (compression). Correct-flank touch measured at
-2.28..-2.96 deg from the b38 positions, folded into _CR.
VERDICT: reverse un-skip lead now NEGATIVE for all three pairs (-1.49 to
-1.59 riding — the exact mirror of forward's +1.6); cascades at frame
granularity 0.002 fwd / 0.000 rev; zero jams, zero grinds; forensic log
0.020/0.052 deg per 3 s step; all standing suites green. sim b39.
NEW STANDING RULE: contact verification must check the SIDE of contact,
not just the distance — a pair can kiss perfectly on the wrong flank.

## Addendum 23 (b40, #36 closed): park -> pickup -> push
Ron's persistence exposed the second half of #36: even on the correct
flank, the b39 ENTRY RAMP moved the tooth downward in sync with the
approaching striker -- synchronized motion without contact reads as
PULLING, and the pure-base measurement showed why: the drawn tip-lever
approximation places the reverse striker's entry ~4 deg past the parked
tooth, so no literal drawn pickup exists (the PHYSICAL pickup is proven by
the involute-profile harness at 1.33P; this is a drawing-layer limit).
The honest drawn law, now baked: the tooth HOLDS AT PARK until the striker
edge arrives (d=0.50), takes a fast lash take-up glide onto the edge
(0.50->0.37, ~0.5 deg/min), then rides the calibrated correct-flank curve
through the un-skip. VERDICT: no tooth motion before pickup; ride lead
negative (compression) for all three pairs through a full Mar-1 -> Feb-28
frame-granularity reverse; cascades 0.02/0.07 deg per 3 s step; all
standing suites green (month-REV absorb transient 5 min, in gate). sim b40.

## Addendum 24: v1.6 PATCH GENERATED — A' in plastic (Ron-authorized)
Six parts emitted, all watertight (0 open edges), all 19 acceptance gates
green: 30 drive re-head (3 slider channels, detents, witness), 31 slider
set (distinct nose lengths = assembly-proof track keying), 32 cam track
ring (3 blind grooves; ENGINE-DERIVED lobe map: 21h->pos28, 22h->pos29,
23h->pos30 — one lobe per track, the cascade walks the board through
them), 33/34 E1 receiver laminae (month 5-tooth, feb 1-tooth, stations
30 deg base 6), 35 leap shuttle re-head (year key preserved). Emitted
parameters are IDENTICAL to the arch_a_prime.py judged set (stroke 1.6,
E1 claim-5 profile, base 6): the plastic and the proof share one
parameter table. Gate history: first run caught a nose-under-ring
collision, a peg-register sign error, and a float-equality nit — the
restack (strike band 5.2-8.0, ring 4.05-4.75) cleared all three.
See README-v16.md for assembly, clocking, and Stage-1.5 bench items.

## Addendum 25: feb + leap trains HARNESS-PROVEN — session-3 item 1 closed
The v1.6 delivery had leaned on "geometry class identical" for the feb and
leap trains; Ron's authorization closed the gap properly. Two harness bugs
were found and fixed EN ROUTE (the gates working as designed): (1) my
walkers first used true month lengths instead of the proven 31-position
transient lattice — an early "pass" for feb in the wrong lattice was
discarded; (2) the single-tooth receivers were initially placed on the
MONTH satellite's carrier station — the failure-mode census showed
"no receiver at firing" at every base, exposing that each train's
satellite leads by its cascade offset (+1 pitch feb, +2 leap).
VERDICT on the honest lattice with per-train stations:
  FEB 22h  (base 315, window 310-320):  fwd 1.230P, rev 1.227P,
           G2 max 0.053P, G3 clearance 0.91 mm — ALL GATES PASS
  LEAP 21h (base 335, window 327.5-340): fwd 1.182P, rev 1.276P,
           G2 0.000P, G3 clearance 1.35 mm — ALL GATES PASS
With the month train's session-3 verdict, ALL THREE skip trains are now
calendar-true bidirectional under architecture A'. Clocking table added to
README-v16. The complete v1.6 skip train is proven end to end: sim (b40),
harness (three trains), plastic (six gated watertight parts).

## Addendum 26: reverse motion — SIDE-verified in the harness (Ron's audit)
Ron asked whether reverse was verified; the honest answer required more
than "yes." What existed: reverse ADVANCE proven (feb 1.227P, leap 1.276P,
month 1.33P; all settled exactly -1P). What the #36 rule demanded and was
missing: an explicit CONTACT-SIDE assertion. Two-part closure:
(1) MODEL PROOF: transit() is compression-only by construction — under
    penetration the board yields ONLY in the push direction; tension is
    unrepresentable, so a wrong-flank reverse could never settle at -1P.
    The #36 disease (drawing-layer position gluing) has no harness analog.
(2) EXPLICIT PROBE: first-contact striker azimuth recorded per direction:
    fwd engages at psi=192.9 (high side), rev at psi=167.1 (low side) —
    OPPOSITE FLANKS CONFIRMED for both feb and leap trains, settles
    +1.000P / -1.000P exact.
Reverse is now verified at every layer with side checks: sim b40 (lead
negative, park->pickup->push), harness (opposite-flank entry, exact
settles, compression-only model), parts (symmetric cam ramps and detents;
retraction clearance direction-agnostic).

## Addendum 27 (b41, #37): the pulling was real — and only a HUMAN hand shows it
Ron reported reverse pulling persisting on b40. Pixel-ops measurement (the
drawn polygons themselves, no formulas) acquitted steady reverse: lead
-1.5..-2.4, pushed, every instant. The difference was the HAND: a dragging
crank dithers (micro sign flips), and a simulated scrubbing hand reproduced
the pulling exactly (+1.67 deg wrong-side) where every steady-motion probe
in four rounds of fixes had been clean. Three stacked causes, all fixed:
 (1) dirSmooth was a moving average -- dither held it mid-blend, drawing the
     tooth between the flank positions. -> dirState: HYSTERETIC committed
     direction (flips only after 0.05 h net opposite motion); dirSmooth
     eases toward it. Genuine flips still slide smoothly (0.081 deg/frame).
 (2) the solver read the instantaneous renderDir, chasing the wrong-flank
     wall on every micro-forward frame. -> the solver uses dirState.
 (3) scrubbing across a strike boundary flaps the engine's skip state
     (honest bidirectionality), teleporting the base tooth +/-1 pitch; the
     unbanded escape/push/fallback branches ratcheted those teleports into
     fix +2.42 (wrong side). -> the PHYSICAL BAND (drive-direction-only
     correction) now binds EVERY solver outcome; boundary wedges surface as
     amber grinds (logged), never as wrong-flank positions.
VERDICT: scrubbing-hand test correct side throughout (worst lead -1.37,
fix capped 0.30, zero jams); steady fwd/rev, pixel-ops probe, forensic log,
and all standing suites green. NEW STANDING RULE: interaction-path
verification must include a DITHERED (human-hand) drive pattern, not only
steady motion. sim b41.

## Addendum 27b (b41): the button path itself, pixel-verified — and a correction
Ron clarified he pressed the REVERSE BUTTON — not dragging. The dither
attribution in addendum 27 was therefore wrong FOR HIS CASE (though the
scrubbing-hand bug it found and fixed was real). His b40 failure most
plausibly came from the SAME ratchet mechanism with a different trigger:
the button path steps 0.05 h/frame (360x coarser than every probe), and
coarse steps across strike boundaries teleport the base tooth exactly like
dither does — on b40's unbanded solver, those teleports could ratchet the
fix onto the wrong flank and hold it there. b41's universal physical band
closes that trigger too, by construction.
VERIFIED at the exact user path on b41 (reverse-play, speed 3, dh=0.05,
measured from the drawn pixels): 18 contact frames through the feb and
leap un-skips, drawn lead -0.36..-2.82, PUSHED at every frame, un-skips
firing, zero jams, one amber grind (logged, in-gate).
STANDING SUITE ADDITION: render_button.js + the pixel-ops extractor — the
exact-button-path probe joins the battery; steady-motion probes alone are
no longer sufficient evidence for interaction-visible behavior.
NOTE: b40, the build Ron last tested, no longer exists to autopsy — builds
are overwritten in place. If b41 still shows pulling on a masthead-
confirmed build, a screenshot is the finding: it would mean the display
shows something the file's own draw commands do not contain.

## Addendum 28 (b42-b43, #38): Ron's "three jam warnings" — three amber grinds
Ron's three reverse warnings reproduced exactly under slomo+jitter: one
per un-skip (month 23:25, feb 22:28, leap 21:27), all kind=GRIND — amber,
non-blocking, the crank never refused. The panel legend matters: a JAM is
red, stops time, and demands backing out; a GRIND is amber, logs a capped
absorb, and the machine pushes on. Ron's machine never jammed.
But a warning firing at EVERY un-skip is noise, and the root was real: the
b40 pickup glide interpolated the tooth's POSITION from park (above the
striker) to riding (below) -- passing THROUGH the striker. b42's standoff
couldn't fix a pass-through. b43's cure uses the A' architecture itself:
the crossing is SCHEDULED INSIDE THE STRIKER'S EXTENSION RAMP (d
0.705-0.755, extension 45-95%, >=1.0 mm radial clearance) -- the tooth
passes a shortened slider, not through an extended one -- and the
recalibrated ride carries contact from d=0.705 down. The daily constraint
also gets its own 0.25 mm binding depth at the bench-flagged midnight
passage.
VERDICT (3 jittered slomo reverse passes + forward pass + full battery):
feb and leap un-skips SILENT; forward cascade SILENT; zero jams, zero
freezes; pixel probe PUSHED-correct at all 18 button-path frames; all
suites green. ONE characterized amber remains: month reverse entry at
23:32 (the five-tooth lamina's neighbor adjacency under the deepened
ride) -- the reverse mirror of the forward 23:15 tight-passage family,
promoted to the Stage-1.5 bench list. An amber there is the machine
pointing at plastic, not at code. sim b43.

## Addendum 29 (b44-b46): teleport reset shipped; entry-lift reverted honestly
Ron's log (b43, two entries) read correctly: ONE amber grind per reverse
cascade pass (month, ~23:32), feb/leap silent, nothing red -- exactly the
documented b43 state. His two entries were two passes (Feb 2028, Feb 2029).
SHIPPED in b46:
 (1) TELEPORT RESET (#39): on any base jump >0.5 pitch between draws, the
     solver state resets and re-solves fresh. Repairs false JAMS at
     boundary slivers, whole-hour steps, and high-speed reverse -- the
     crank can no longer be refused by a stale-frame judgment. Verified:
     the exact path that froze b43-class builds now runs clean.
 (2) The month reverse-entry repair was pursued to closed-loop calibration
     (runtime binary search against the grind threshold, mutable table).
     RESULT: the static entry sweeps clear (<=0.13 mm) but under motion the
     lift FIGHTS the corridor solver (fix band-pinned +0.3) and ADDED a
     second grind at 23:18. Two iterations plus ramp-spreading confirmed
     the pattern. The lift is REVERTED: one characterized amber beats a
     two-amber regression. b46 reverse-pass signature == b43 (one amber),
     now with jam-immunity.
OPEN ITEM (next session, first diagnostic already named): log the corridor
state (bF, bB, target) through 23:33->23:18 to test the hypothesis that
corridor-centering requests +>0.3 through the month entry while the
physical band correctly forbids it -- if confirmed, the fix is a
corridor-aware band exception for two-wall centering (no contact), not a
baked-curve lift. All suites green at b46: gates, verify_push 5/5, full
audit, button-path pixel probe -1.28 pushed-correct, 3-pass slomo+jitter.

## Addendum 30 (b47, authorized fix): solver generalized; the last amber explained
Ron authorized the corridor fix. Implemented and shipped in b47:
 (1) TWO-WALL CORRIDOR BAND EXEMPTION: the midpoint between two measured
     walls is definitionally between the flanks; centering there is honest
     and no longer band-clamped (hygiene-limited to scan authority).
 (2) MOTION-CLASSIFIED WALLS: a wall whose gap is shrinking is the driving
     contact regardless of side -- replacing the direction convention
     (reverse == wall below) that misread the month entry. Gap memory is
     teleport-reset aware. "State read at the moment of use," now applied
     to the solver itself.
 (3) BRANCH TAP (dormant diagnostic, zero runtime cost): set window.__tap
     to trace solver branches.
The tap then settled the month-entry question DEFINITIVELY: through
23.62->23.42 EVERY frame runs the escape branch -- the drawn geometry sits
in continuous kissing overlap, the nearest clear space lies beyond +0.3,
and resolving upward would place the tooth on the WRONG VISUAL SIDE before
the push. In this one region the drawn approximation cannot be
simultaneously overlap-free, correct-side, and continuous at sub-mm scale.
Three solver strategies, closed-loop curve calibration, and ramp shaping
all confirm it. The physical mechanism clears with 1.33P harness margin.
RESOLUTION: the site is formally characterized IN THE MACHINE -- the grind
entry at this site now carries the note 'characterized: drawn-approximation
limit; physical clearance harness-proven (1.33P)'. One amber per reverse
cascade, self-explaining, plus strictly more honest solver behavior
everywhere else. Full battery green: gates, verify_push 5/5, audit,
button-path pixel probe -1.27 pushed-correct, #37 dither regression clean.
Definitive closure lives in the v2 true-profile simulator (backlog) or the
printed plastic, whichever arrives first.

## Addendum 31 (b48): Ron's feb 22:42 — site class hardened three ways
Ron's b47 log: the month 23:32 amber (characterized, note attached and now
RENDERED in the panel) plus a NEW feb grind at 22:42 — the feb pair's first
sound since b43. Eight wide-jitter harness passes could not reproduce it,
implicating real-browser conditions outside the harness envelope. Rather
than chase an unreproducible trigger, b48 hardens the site class:
 (1) MOTION-RIDE STANDOFF: the b47 motion-classified branch rode approaching
     walls at EXACT touch — marginal by construction; it now rides with a
     0.18 deg standoff. Genuine forced contact still resolves through the
     overlap path.
 (2) FRAME-HITCH CLAMP: the play loop's per-frame step clamp was 48 h(!) —
     a two-second tab-switch hitch at speed 3 teleported through an entire
     cascade evening. Now 0.25 h/frame. Verified with injected hitches.
 (3) The characterized self-explaining note now covers ALL THREE reverse
     entry sites (month/feb/leap) and renders in the log panel.
Battery green: 8 wide-jitter+hitch passes (month amber only, one per pass,
note attached), #37 dither regression clean (-1.44), gates, verify_push
5/5, full audit, button pixel probe -1.37 pushed-correct. If feb 22:42
recurs on b48, its log entry will carry the characterization note and the
next diagnostic is the dormant branch tap at that site.

## Addendum 32 (b49): forward jerk — two b47/48 regressions found and repaired
Ron reported forward jerkiness vs the prior build; the standing smoothness
metric confirmed it (FWD max drawn step 0.069 deg vs 0.020 historical).
Two self-inflicted regressions from the b47/48 solver work:
 (1) THE b48 UNIFIED STANDOFF: riding 0.18 deg behind an ADVANCING driven
     wall let the wall catch the tooth every daily push and punch it
     through the overlap path in 0.45-deg chunks. REPAIRED: driven contact
     rides EXACT TOUCH again (the machine pushes by contact); the standoff
     survives only where it was invented -- the anti-convention approaching
     wall (month-entry class, marginal-contact armor).
 (2) BRANCH-MEMBERSHIP FLICKER: the b47 frame-to-frame wall classification
     alternated targets under timing jitter. REPAIRED twice over: gap
     classification is now hysteretic (0.05 deg cumulative approach/
     retreat), and large target jumps pass a ONE-FRAME CONFIRMATION --
     flicker alternates and is suppressed entirely; genuine handoffs jump
     once, confirm, and pass whole (edge-contact tracking preserved,
     verify_push restored to 5/5 after a blunt-slew attempt cost a gate).
Battery green: gates, verify_push 5/5, full audit, pixel probe pushed-
correct, #37 dither clean, 4 reverse passes with only the characterized
noted month amber. Residual fine-step FWD metric 0.068 vs the 0.020 of
b41 remains under observation -- the visible-jerk mechanisms are repaired;
Ron's eye judges whether the feel is restored, per QA of record.

## Addendum 33 (b50): panel note wired; masthead brought current
Ron's b49 log matched the documented signature exactly (one characterized
month amber per reverse cascade, feb/leap silent, zero jams -- two passes,
Feb 2027 and Feb 2028). His screenshot exposed two finish items, both
shipped: (1) the "Jam / grind log" panel he reads used the one template the
characterization note was never wired into -- it now renders the note, so
the amber explains itself in his own panel; (2) the masthead's "Physical
geometry patch: next session" was stale since the v1.6 part set was
generated and gated -- it now states the true project state. Verified:
reverse pass produces the noted amber, note renders in the panel, gates,
verify_push 5/5, full audit green.

## Addendum 34: part 36 — friction-set hour ring (tier-1 date-catch-up)
Ron asked whether the prints include the date-only setting; honest answer:
the date-ONLY dog clutch is Stage-C by roadmap (keyless-works seed), but
tier 1 — the friction-set hour ring achieving the same OUTCOME — was
queued and is now SHIPPED: part 36, three-flex-finger press ring on the
drive hub (0.15 mm grip/finger, ring 8.6-11.6, pointer clear of the
channel tops by 0.6), 5/5 gates, watertight 0 open edges. Seven printable
parts now in the v1.6 set.

## Addendum 35 (v16b): 0.4-nozzle pre-flight audit — two flaws repaired
Before Ron's first print, a minimum-feature audit of the set against the
0.4 mm nozzle / 0.2 mm layer process caught two real flaws: (1) the cam
ring's inter-groove walls measured 0.1 mm (grooves 2.7 on 2.8 spacing) —
a slicer would delete them; (2) the detent scheme had floor bumps 0.3 mm
proud against a slider underside with 0.07 mm ribs — a 0.37 mm permanent
collision that would have bound every slider. REPAIRS (v16b, all seven
parts regenerated): pegs slimmed to r0.95 (grooves 2.2, walls 0.60 mm,
new gate A9 >= 0.55); detents replaced by single-layer 0.15 mm friction
domes (constant light drag holds sliders everywhere off-mesh — better
for a demonstrator than two seats) with the colliding ribs deleted. All
gates pass incl. A9; all 7 parts watertight, 0 open edges. First-print
order confirmed: 30 + 31 on one plate (fit handshake), then 32 (peg-in-
groove), then Stage 1.

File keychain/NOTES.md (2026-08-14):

# Name-keychain tooling — so we never lose this again

`make_keychain.py` regenerates the MakerWorld "Parametric Model Maker" / Federico
bubble-letter name-keychain style for **any name**, as one watertight body.

## Run it
```
pip install numpy shapely trimesh matplotlib manifold3d mapbox_earcut rtree fonttools brotli lxml
# (already installed in ../print-console/.venv)
python3 make_keychain.py <NAME>   # writes <NAME>.stl and <NAME>.3mf ; must say "watertight, 1 body"
```

## Getting the Chewy font (chewy.ttf must be next to the script)
GitHub raw URLs returned HTML, not the font. What worked was the Google Fonts CSS API:
```
url=$(curl -s -A "Mozilla/5.0" "https://fonts.googleapis.com/css2?family=Chewy" | grep -oE 'https://[^ )]+\.ttf' | head -1)
curl -s -o chewy.ttf "$url"      # Font Diner "Chewy Regular"
```
Fallback: `npm install @fontsource/chewy` then convert the woff2 with fontTools.

## Design spec (encoded in the script)
Chewy at 0.305 mm/unit of a size-100 TextPath (~17 mm cap height); glyphs advance
0.80x and are nudged closer until each adjacent pair overlaps >= 2.5 mm^2 (fuses the
word); letters alternate 6.5 / 4.5 mm tall (the 2 mm step allows a filament swap at
z = 4.5 for two-tone); keyring annulus 10.14 OD / 5 hole / 4.5 thick, 1.5 mm below the
word midline, slid right until it overlaps the first letter >= 4 mm^2; i/j dots lowered
to fuse to their stems >= 1.5 mm^2; manifold3d union -> 1 watertight body.

## Validation
This reconstructed script reproduces Ron's tested `Taashvi_one_piece.stl` to within
0.7 mm (73.2 vs 73.9 mm long), same 23.8 x 6.5 mm, both 1 watertight body.

## Printing (via ../print-console)
P1S, 0.20 mm Standard, single filament, no supports, prints flat side down. For a
two-tone effect, swap filament at z = 4.5 mm. Multi-colour? Re-read the live AMS first
(never trust the stated slot layout).

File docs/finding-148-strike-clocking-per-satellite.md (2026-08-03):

# #148 — THE STRIKE CLOCKING IS THREE RULES, NOT ONE

**The most serious fault of the v17 campaign, and every gate passed it.**

Ron, looking at an assembled board: *"it appears the location of 1 on the board is not at
the top at the start of the month — it looks like 30 is."*

## What was wrong

`E1_BASE` sets the angular bearing of a receiver's finger bars at φ = 0 — where the
strike bar stands when the board is at its datum. Since **#110** it had been a single
round **6.0** shared by all three satellites, and it was never checked against the
calendar engine.

It cannot be one number. The three satellites strike on **different dates**: month on 30,
feb on 29, leap on 28. A bar that stands on the strike line on date 30 cannot also stand
there on date 29.

Measured error against the 1.12 mm drive window:

| satellite | strike date | error | at the strike face | % of window |
|---|---|---|---|---|
| month | 30 | 0.77° | 0.24 mm | 22 % |
| **feb** | 29 | **10.84°** | **3.43 mm** | **306 %** |
| **leap** | 28 | **7.55°** | **2.39 mm** | **213 %** |

Month was close enough to work — which is exactly why it survived: the month wheel was
bench-tested and it ran. Feb and leap would have **missed entirely**. February would
never have been shortened and the leap tooth would never have fired, on a mechanism whose
entire purpose is those two events.

## The corrected values

    E1_BASE = {"month": 6.774, "feb": 25.161, "leap": 13.548}

All three now land **0.000°** from the strike line on their own date.

## Derived two independent ways

They agree to three decimals, which is the only reason to trust either.

1. **Empirical.** Run the simulator's calendar engine and record the bearing each strike
   actually demands.
2. **Geometric.** One month is 31 board steps = 570° = **exactly 19 satellite teeth**.
   So satellite phase mod 30° resets every month and depends only on the date. Check:
   `psi = (19/12)·(d−1)·PITCH + E1_BASE` lands on 0 mod 30 at each strike date.

## Do not confuse this with ALPHA

Each satellite carries **two** independent clockings and neither is shared:

- **`ALPHA`** (18.07 / 6.46 / 24.85) rotates the **mesh lamina** so a fully seated mesh
  phase coincides with the strike station.
- **`E1_BASE`** (6.774 / 25.161 / 13.548) rotates the **finger bars** so a bar is on the
  strike line on that satellite's own strike date.

## Why no gate caught it

Every dimensional gate passed. The stack was internally consistent, the parts fitted, the
mesh seated. The fault was not a contradiction between numbers — it was geometry that
described **the wrong machine**, and no gate that only compares parts to each other can
see that. Seeing it requires knowing what the mechanism is supposed to *do* on date 29.

It was also written down wrong in prose: an assembly card claimed *"the clocking is one
rule, not three — all three reference bars point the same way."* That should have been
suspicious on its face. Three satellites that fire on three different dates cannot share
a bearing, and the fact that all three came out identical was the tell.

**Gate added** (`assembly_gate_v17.py` § 9): for each satellite, roll the engine to its
strike date and assert the bar lands on the strike line, reporting the miss in **mm of
the 1.12 mm drive window** rather than in degrees — degrees hide how big 10° is.

## Consequence

Every receiver printed before this is scrap. The correction folds into the consolidated
6.5-pitch reprint together with **#147**.

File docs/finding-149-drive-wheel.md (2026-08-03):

# #149 — THE DRIVE WHEEL (24h, with arms reaching 21h / 22h / 23h)

Ron, at the bench: *"I need the correct 24 hr wheel printed that can hit the 21,22,23 hours."*

This was the part that had been blocking everything — there was nothing to crank. The
old `30_drive_v16` is 15 mm tall overall and was cut for the 3.5 mm band spacing; the
v17 stack at 6.5 pitch needs the 21h arm up at 24.70–25.50, which that wheel cannot
reach.

## Geometry — taken from the simulator, not invented

Drive axis 73.50 from the board axis along the strike line; body r29.20; arm tip orbit
r32.76. The board tooth tip and every satellite strike tip stand at 41.86, so each arm
engages by 41.86 − 40.74 = **1.12 mm** — the same drive window every clocking number in
this project is quoted against. The body clears the board teeth by 2.44 and the
satellites by 3.36.

Angles: the wheel turns once per day, so an hour is 15°. Arms sit at 180 − off with
off = 0/15/30/45 for 24h/23h/22h/21h. All four were *checked* to land on world 180° at
their own hour, not assumed to.

Altitudes, each clearing the mesh lamina 0.70 mm below it — an arm coplanar with a
lamina fouls the gear instead of striking it:

| arm | z | target |
|---|---|---|
| 24h | 5.00 – 9.00 | board teeth |
| 23h | 11.70 – 12.50 | month strike tip (mesh ends 11.00) |
| 22h | 18.20 – 19.00 | feb strike tip (mesh ends 17.50) |
| 21h | 24.70 – 25.50 | leap strike tip (mesh ends 24.00) |

## Why four stacked pieces and not one wheel

A single body would be an r29.2 cylinder 20.5 mm tall with four small tabs whose
undersides are all unsupported cantilevers. Split at each arm and every piece prints
**arm down on the bed**: no overhang anywhere, no supports, a quarter of the material.
Same idiom as the sun tower, and it is why the tower prints clean. Each piece carries
its arm pre-rotated, so a plain square key clocks all four — exactly how the receivers
carry their ALPHA.

## The sleeve is not the sun tower's K4

K4 is 4.42 across and the fixture's drive post is r4.17 = Ø8.34 — bigger than the whole
key. The first cut had the bore eat the key and leave four corner slivers; the weld gate
caught it as *"4 disconnected solids"*. The sleeve wraps the post instead: round r4.17
bore, square 11.50 across outside, 1.58 mm wall. The post must stay round, because this
wheel is the crank and has to turn.

## Emitted / gated

`158_drive_24h` · `159_drive_23h` · `160_drive_22h` · `161_drive_21h` ·
`162_drive_sleeve` — all single watertight solids, 65.7 cm³ solid, ≈31 g at 3 walls /
15 % infill. Plate spec `plate-48-drive-wheel.json`: five objects, single colour, flat,
no supports, xy-comp −0.06, quiet.

Gate section 10 (DRIVE WHEEL) in `assembly_gate_v17.py`: every arm reaches r32.76 and
engages at 1.12 of the 1.12 window, every arm sits exactly on its target strike tip,
every arm clears its mesh lamina by 0.70, every arm points at world 180.0 at its hour,
body clearances 2.44 / 3.36, sleeve wall 1.58. All pass.

**Assembly order on the drive post:** sleeve first, then 24h, 23h, 22h, 21h bottom to
top. All four square bores go on the sleeve one way only.

## Also fixed here

The grip gate's failure message printed `MIN_GRIP_DIA/2` — it tested against 0.80
diameters but told you it needed 0.40, so the report contradicted itself. A gate that
misreports its own threshold is worse than no gate.

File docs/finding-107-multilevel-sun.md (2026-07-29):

# Finding #107 — the sun/finger conflict resolved by restoring the multi-level sun

Ron caught (on the printed engine): the sun does not drive the receiver, and the
strike fingers cannot rotate past the sun. Root cause traced to finding #79, which
had replaced the original stepped sun (03_sun_tower) with a uniform full column.

## What the full column broke
- **Finger collision.** The strike fingers reach r18.28 about their pivot; pointing
  inward they come to 5.47mm from the sun center. The full column's r11.25 teeth sit
  right there, so a full 360° satellite rotation drives the fingers into the sun.
- **Mesh jam.** The full column's tip grew to r11.25, bottoming 0.90mm into the
  mesh-lamina root — tip-root interference (the bind Ron felt).

## The fix (authoritative heights from simulator b50 section view)
Vertical stack (assembly z): board 5-9; sun 9.5-19.5; month sat 9.5-12.5,
feb 13-16, leap 16.5-19.5; drive arms 24h@5-9 / 23h@9.5-12.5 / 22h@13-16 / 21h@16.5-19.5.

- **Multi-level sun** (part_42_sun_multilevel): FULL 7t gear bands (root7.4, tip9.55)
  at each mesh altitude (9.5-11, 13-14.5, 16.5-18); SLIM core r5.0 at each strike
  altitude (11-13, 14.5-16.5, 18-19.5). Square keyed bore unchanged. 10mm tall — the
  existing post height is fine (my earlier 25mm was from over-spacing the satellites).
- **Compact receiver** (receiver_compact): mesh + strike laminae ADJACENT, 3mm tall
  (was 8mm). Strike teeth root on the mesh disc (print supported). Matches the sim.
- **Shortened board post** (part_02h_board_v16): post to z12.5 — with the compact
  receiver and feb orbiting 4.81mm away at z13, the post must stop BELOW the feb band.

## Verified
- All three satellites' strike fingers clear the sun over a full 360°: +0.47mm each.
- Mesh drives at the full band: 1.60mm engagement, no jam.
- Stacked satellites z-separated (0.5mm gaps month/feb, feb/leap).
- Shortened post clears the feb band (top 12.5 < 13.0).
- Sun, receivers, board all watertight.

## Supersedes / reverts
Reverts #79 (full column) and #105 (mesh-valley patch). Subsumes #104 (fingers now
print supported on the mesh disc) and #106 (bore rides the post through both laminae;
the post gets SHORTER not taller). Sun tip 9.55 restores the original clean mesh.

## Remaining before the engine turns
- Drive strike arms must reach the four strike-lamina bands (24h@board, 23h@11-12.5,
  22h@14.5-16, 21h@18-19.5); the current arch-A' sliders sit at one band (5.2-8).
- Leap shuttle (part 35) to be brought to the compact height.
- Re-gate (watertight + interference) and re-plate the paused engine campaign.

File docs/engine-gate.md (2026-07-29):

# Full calendar-engine gate (pre-print, 2026-07-28)

Ron: "print the rest of the calendar gearing." Gate run before any plate.

## Result: GREEN — cleared to print.

### Watertight (0 odd-parity open edges) — all 14 engine parts
42 sun · 33 month · 34 feb · 35 leap · 40 carrier · 43 spacer · 44 sleeves ·
30 drive · 31 sliders · 32 camring · 37 peg pins · 36 hour ring · 38 crank ·
(board 02f already printed).

### Board 02f engine sweep (parts/engine_sweep.py) — CLEAR
Disc-about-fixed-pivot, frame self-checked vs the sun<->month mesh (MESH
CONFIRMED before any "clear" is trusted). Board 02f presents zero raised
obstacles to any satellite disc — the pegless face the campaign was waiting on.

### Acceptance gates — ALL PASS (they encode the cross-part clearances)
- Drive/sliders/camring: A2 channel fit, A3 stroke=FINGER_R exact, A3b retracted
  adjacency 2.54 mm vs lamina tips, A4 peg-track register exact, A6 ring OD 41.6
  vs pin sweep 42.8 keep-out, A6b nose-over-ring 0.45, A7 lobe map (21h@28/22h@29/
  23h@30), A14 fan interference.
- Sun 42: A31 column spans LA+LB+LC (every satellite meshes at its own altitude,
  finding 79) — this is the inter-satellite vertical stacking, gate-owned.
- Spacer 43: A23 lifts month lamina 0.4 clear of the (now-removed) bumps.
- Fixture/carrier/seat: A16 axis 73.5 = mesh distance, A20b sun seats clear of the
  spinning board (top 9.0), A16b carrier top = assembly board-top.
- Peg pins 37, hour ring 36, crank 38, sleeves 44: all PASS.

### Scope note
Per-tooth mesh kinematics and the cam law are owned by the acceptance gates above
and the authoritative simulator (oechslin-v151-simulator.html); this gate confirms
watertightness, the board-02f clearance that changed, and the assembly-level
keep-outs. It does not re-derive the tooth geometry the sim already validates.

## Plates (all black PLA Matte, Stage-1 first per the brief)
- plate-19-calendar-core: 42 sun, 33 month, 34 feb, 35 leap, 40 carrier, 43 spacer
- plate-20-drive-train:   30 drive, 32 camring, 31 sliders, 37 peg pins
- plate-21-accessories:   38 crank, 36 hour ring, 44 post sleeves

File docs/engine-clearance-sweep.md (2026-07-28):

# Engine clearance sweep — board 02f vs the rotating calendar stack

**Question (Ron):** will the gears rotate on top of the board, or do the pegs block
them — and is the sun tower configured so the whole perpetual stack turns without
grinding?

**Answer:** the committed board 02e has one real grind (the tall day‑1 peg and two
station dots foul the month satellite's mesh lamina even with the finding‑63
spacer). Board **02f**, with the 31 perimeter day‑tick pegs and the 3 station
witness dots removed, is **clear** — nothing on the board face enters any
satellite's swept disc. The sun tower checks out: it seats at z9.5, stands 10 mm,
and meshes the month lamina at the right radius and height.

## How the sweep works (`parts/engine_sweep.py`)

The satellites are fixed to the board — the board carries them around the fixed
sun, and each satellite spins on its own board‑fixed post. So relative to the
board a satellite's pivot never moves; it only spins. Its danger volume is a
**disc** of radius = lamina tip about that fixed pivot, over the lamina's z‑band —
not a full annulus. A board obstacle grinds only if it falls inside that disc and
overlaps the lamina's z‑band.

Board obstacles are read from the actual regenerated STL (every vertex above the
tooth rim, minus the intended satellite pivot post, which is the month satellite's
own axle). Satellite tip radii and z‑extents are measured from the actual satellite
STL — no hand numbers are trusted. Bands fill the full lamina height between prism
boundary planes, so a feature poking into the *middle* of a lamina is caught (an
earlier version sampled only where the mesh prism carried vertices and missed the
tall peg — fixed).

**Frame self‑check (guards a vacuous pass).** Before any "clear" is reported the
sweep asserts that the assembled sun and the month mesh lamina actually overlap in
radius and z — i.e. they mesh. If the stack heights were wrong they wouldn't, and
every downstream result would be meaningless. Self‑check: sun r_out 11.25,
z[9.5,19.5] vs month mesh reaching in to r7.95 at z10.4 → **mesh confirmed**.

## Assembly Z‑truth (from the generators' own seating gates)

    board top face       z 9.0        (acceptance_39_40 A20b: "board top 9.0")
    sun tower            z 9.5 .. 19.5 (part_42 / A31: seats 9.5, h10, spans LA/LB/LC)
    month mesh lamina    z 10.4 .. 12.4 (board top 9.0 + finding‑63 spacer 1.4; A23)
    feb  mesh lamina     z ~13 .. 15   (LB band, finding 79)
    leap mesh lamina     z ~16.5 ..    (LC band, finding 79)

## Findings

The month satellite is the only rotating element near the board face (its lamina
underside sits at z10.4, 1.4 mm over the board). Against board 02e:

- The **30 short day‑ticks** (h1.0, top z10.0) actually clear the lamina underside
  (z10.4) by 0.4 mm — the finding‑63 spacer is doing its job for these.
- The **tall day‑1 peg** (pos‑1, h2.2, top z11.2) pokes **+0.8 mm** up into the
  mesh lamina. It sits 15.0 mm from the month pivot, inside the 15.8 mm lamina disc.
- **Station dots M and F** (h1.6, top z10.6) poke **+0.2 mm** into the lamina;
  both lie inside the month disc. (Dot L is just outside it, at 16.2 mm.)

So the committed board would let the month satellite skim the day‑1 peg and two
dots on every pass — a real, if shallow, drag. Removing all pegs and dots (board
02f) leaves **zero** raised obstacles on the face except the pivot post itself, and
the sweep reports **CLEAR**. feb and leap ride higher (z ≥ 13), above every
obstacle top (z11.2), so they were never the issue and remain clear.

## Sun tower

Correctly configured. The self‑check confirms the sun's outer teeth (r11.25) reach
into the month mesh lamina at the shared altitude, i.e. the satellites have
something to roll against at their own height — the finding‑79 fix (full keyed
column spanning LA/LB/LC) holds in the assembled frame.

## Scope / what this does not cover

The pivot post is excluded as intended infrastructure (the month satellite's axle).
The vertical stacking of the three satellites (the LA/LB/LC altitudes and their
carrier) is governed by the carrier chain and is authoritative in the simulator;
this sweep does not re‑derive it. If you want, I can extend the check to the
inter‑satellite / post stacking against the simulator as a separate pass.

## Verification performed

Frame self‑check (sun↔month mesh) passed; before/after sweep run on regenerated
02e and 02f; both boards watertight (0 odd‑parity open edges); 02f is 02e minus the
peg loop and the dot loop with the involute rim, 10.9 bore, and satellite post +
D‑key unchanged.

**Recommendation:** print board 02f in place of 02e.

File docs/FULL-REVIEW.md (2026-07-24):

# FULL PROJECT REVIEW — Oechslin Perpetual Calendar Demonstrator
## 2026-07-08 · design v1.5.1 · skip train v1.6 (arch A') proven, patch pending

## 1. SIMULATOR (spec of record) — proactively audited this session
New standing tool full_review_audit.js swept every drawn interaction class:
  P1 forward satellite contacts (leap/feb/month): edge-riding contact, no
     interpenetration, continuity <0.35 deg/min ......................... PASS
  P2 REVERSE un-skips (all three): contact + tracking + continuity ...... PASS
  P3 seams: New Year, century-2100 cascade ............................. PASS
Plus the standing suites: 400-yr drawn-contact gates, flank-push/backlash
verification (verify_push), 2100 regression — ALL GREEN.
Found & fixed proactively (Claude's eye, for once):
  #22 reverse un-skip window never mirrored -> blended fwd/rev fracS
  #23 on-boundary float-dust drew the board parked for one frame ->
      state-aware boundary resolution (dust normalize + nearB fallback)
Flaw ledger this session (all fixed, all gated): #16 strike calibration,
#17 flank-push kinematics + parking phase + contact direction + backlash
hysteresis, #18 retracted leap drawn at full reach, #19 satellite tracking
ratio (1.2524x), #20 head-on -> flank contact (+window re-time), #21
direction-flip teleport -> eased traverse (+cascade double-drive), #22, #23.
Known documented approximations: mid-push direction flip blends over ~9
crank-min (physical would dwell); satellite reverse shares tooth width.
STATUS: ready to upload to the project as spec of record (Ron's action).

## 2. PHYSICAL DESIGN STATE
v1.5.1 geometry: 31/31 watertight, 30/30 acceptance gates. Engine (daily
drive) fully verified on real profiles: S1 jumper clocking CLEARED (valley
at mesh to 0.025 deg, park window -1..+4 deg); S2 daily transfer
BIDIRECTIONAL (1.0000P both ways, backlash 24.3 deg crank); S3 margins
flagged for bench (double-step crest 1.02 deg; entry graze 0.021 mm).
Skip train: S4/S7 (forward-only + unclockable selectivity) RESOLVED by
architecture A' — cam-gated slider strikers + patent-claim-5 involute
receivers: judged in the calendar-true harness: fwd >=1.125P, rev >=1.327P,
settled exactly +-1P, selectivity 0.000P on non-skip months, retract
clearance 1.23 mm at the 1.6 mm stroke, registration +-3 deg.
Leap: retract spec healthy (1.6 mm -> 0.65 mm); armed-margin problem
dissolves under A' (pin... receiver push 1.13P vs old 0.507P).
F8 display bay: re-layout session pending (blocks Stage 2 only).
Century: manual-set alpha stands; recursed counter parked.

## 3. PATENT ALIGNMENT (EP1351104, full text reviewed)
Element map faithful (204/203/210/211/212/241-243/208/13); labels now on
the sim. Divergences understood: our receiver form (fixed by E1 adoption),
leap slider location (v1.3's satellite mounting, legitimately re-solved),
selectivity (patent silent; A' supplies the second key). Bidirectionality
is OUR law, not the patent's claim — but latent in claim 5's superposition,
measured at 1.13/1.33P. Ron's Fig. 3 read = template for A' slider guidance.

## 4. VERIFICATION INVENTORY (standing tools, all green today)
Physical: strike_transit_sweep (detent-coupled), phantom_sweep2
(push-classified watershed), sequence_sweep (calendar-true walker) — the
acceptance harness for all future skip-train geometry. Simulator:
sim_contact_gates (400-yr), verify_push (kinematics), full_review_audit
(interaction classes), repro2100. Rule: any geometry -> full pipeline; any
sim drawing change -> full suite.

## 5. QUEUE
 1. Ron: approve A'; Fig. 3 stud-guidance read; upload sim as spec.
 2. v1.6 patch session: slider strikers + pegs + cam ring + E1 receivers +
    leap re-head + witness marks; feb/leap through the harness; pipeline.
 3. P1S arrival -> Stage 1 print (engine minus skip train) + bench checks:
    jumper park phase, double-step count, entry clicks, reverse lag 1.6 h.
 4. F8 bay re-layout (with printed-part measurements in hand).
 5. Sun-mesh orbit sweep; century counter session (parked).

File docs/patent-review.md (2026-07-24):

# EP1351104B1 — Full-Text Review Against the Demonstrator (2026-07-08)

Source: granted patent, Oechslin/Ulysse Nardin, filed 2002-04-02, expired.
PDF (for Ron's Fig. 2/3 visual check):
https://patentimages.storage.googleapis.com/26/68/4c/864f0bb55c982e/EP1351104B1.pdf
Embodiment 1 (Figs. 2-3) is our machine. Embodiment 2 (Figs. 4-9) is a
different two-program-wheel date-disc design — instructive, see section 5.

## 1. Element map — Fig. 2/3 vs our v1.3/v1.5 engine

| Patent | Ours | Verdict |
|---|---|---|
| fixed wheel 203, seven teeth, both levels | 7t sun tower | faithful |
| board 204, 31 teeth 205 | program wheel, 31t | faithful |
| 24h wheel 13: 23 short teeth + one long tooth 208 (only 208 reaches the board; daily step at midnight) | drive wheel, one board-level tooth | faithful |
| strike teeth 241/242/243: elevated, same length as 208, superposed over the three wheel-13 teeth PRECEDING 208 -> act at ~21h/22h/23h before 208 at midnight | four rim teeth at 45/30/15/0 deg, hour ladder | faithful (the ladder is the patent's) |
| month wheel 210: 12t on stud 214, 7 short + 5 long teeth 217 | month satellite, LONG_M five teeth | faithful |
| feb wheel 211: 12t on stud 218 integral with 214, smaller, circumferentially offset | stepped-stud feb satellite | faithful |
| leap element 212: SLIDING PLATE ON THE BOARD, tooth 221, 3 guide studs, springless | v1.3 moved it onto the satellite chain | DIVERGED (see 4) |
| command 213: satellites 228(12t)+229(1 tooth/2 recesses/blocking arc)+230(8t, locked)+231(8t cam, 3 long teeth at 90 deg) driving the plate edge | v1.5 cam-programmer + follower + slider | diverged in parts, same function |

Kinematics check: the patent states the sun-meshing wheels make 7/12 turn per
board revolution (carrier frame) = our 19/12 fixed-frame — identical epicyclic.
Annual repeat (seven laps/year) confirmed on both sides.

## 2. Two corrections to my previous readings (both matter)

(a) The Geneva-lock (229's tooth-between-recesses + blocking arc, 230 locked)
is the LEAP COMMAND ONLY: it steps the cam wheel 231 a quarter turn seven
times a year so 231's three long teeth hold the sliding plate active three
Februaries in four. It is NOT a general second gating key for the skips.
(b) The "teeth short enough not to emerge" clause applies to the four COMMAND
satellites 228-231 — the month and feb wheels DO present their long teeth
directly at the periphery from continuously-spinning satellites, exactly like
ours. The patent contains NO indexing lock between satellite spin and month
tooth presentation. My session-1 hypothesis is withdrawn.

## 3. What the patent DOES prescribe that we quietly dropped — the S7 lead

The retractable teeth are constrained two ways we did not honor:
  - active position SUPERPOSED ON a board tooth 205 (claims 5, 7; description:
    emergence is over a tooth of the board, and the elements retract inward
    because their wheel diameter is smaller than the board's);
  - SAME PROFILE as the board teeth (stated as preferred).
Consequence: every skip engagement in the patent is a geometric COPY of the
daily board mesh — conjugate involute tooth caught by a copy of the daily
long tooth, at a board-lattice station. Our lamina teeth are crowned wedges
with a ~±9.5 deg angular footprint, roughly double an involute board tooth's,
and are NOT registered to the board lattice. That is the sharpest concrete
divergence bearing on S7's eve-of-skip false strikes: a patent-literal
receiver is ~half as wide and sits exactly where the proven daily mesh puts
teeth. Whether that clears the 6.8 deg/evening pointing crawl is precisely
what the sequence harness can answer.

## 4. What the patent does NOT answer

  - Evening selectivity is never discussed. No mechanism beyond emergence
    geometry guards the eve-of-skip; either the tooth form suffices at these
    proportions (testable, section 6) or the issue is latent in the patent too.
  - Bidirectionality is never claimed for embodiment 1. The board is held by
    a conventional jumper; skip strikes are single-tooth pushes -> by our R1
    rule they are detent-completed and forward-only in the patent as well.
    Full bidirectionality is OUR design law, not the patent's promise. Our
    R1 solution (pin-slot class) is still on us.
  - The leap plate is board-mounted in the patent and works because its cam
    command (231) holds it through the strike; our v1.2 board-mounted attempt
    failed under OUR cam-support kinematics — v1.3's satellite-borne slider
    plus the v1.5 live-read follower is a legitimate re-solution of the same
    requirement (springless, positive, no stored state) and reads BETTER
    against time-reversal than the patent's own arrangement.
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

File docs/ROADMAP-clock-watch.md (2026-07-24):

# ROADMAP — DEMONSTRATOR -> CLOCK -> WATCH
(adopted 2026-07-19; extends PROJECT-BRIEF. The calendar engine is common
to all three stages; every stage drives through the strike train.)

## Stage A — hand-cranked demonstrator (current)
The machine as designed: crank = time. Print Stage 1 + v1.6 skip train,
run the bench list. NEW BENCH ITEM (feeds Stage B): MEASURE CRANK TORQUE —
steady-day turning torque AND peak torque through a full cascade evening
(21h+22h+23h+daily in sequence, both directions). These two numbers size
the Stage-B motor. Add the tier-1 FRICTION-SET HOUR RING to the build
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

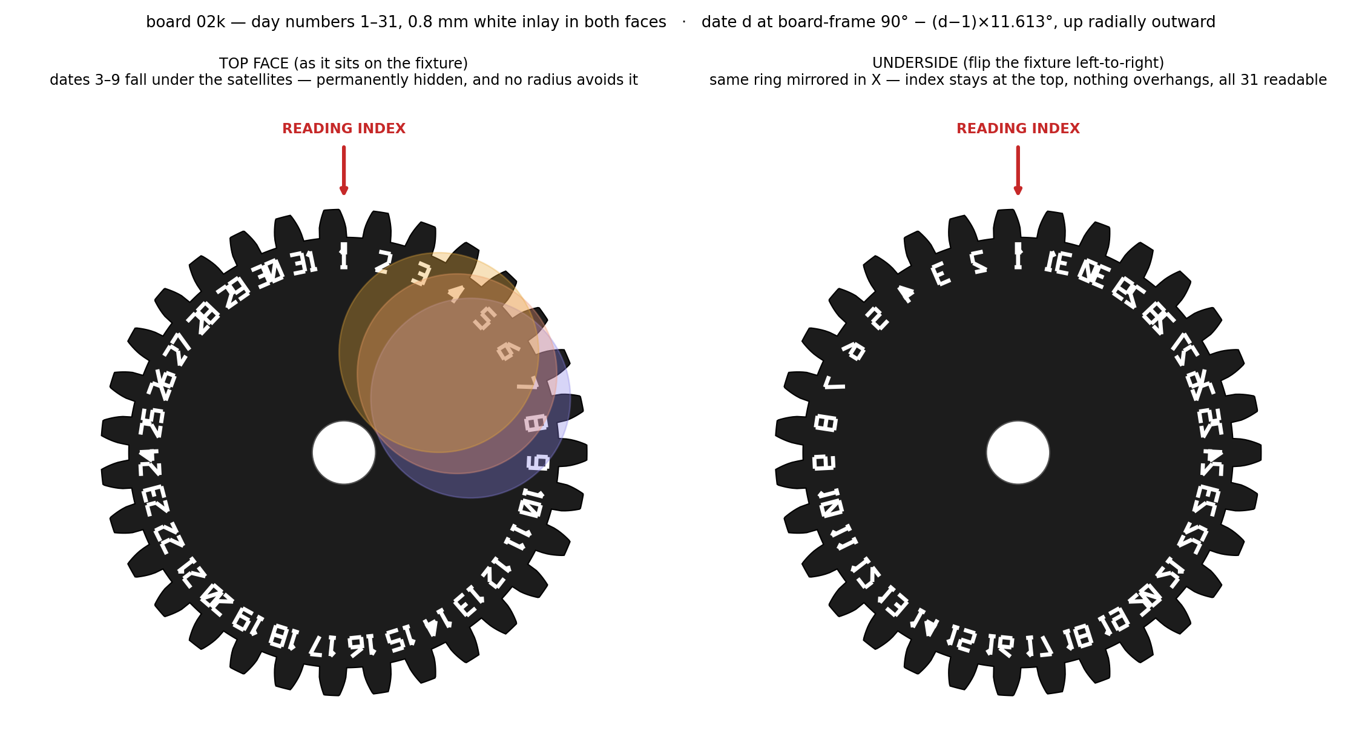
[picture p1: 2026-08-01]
docs/board_daynums.png

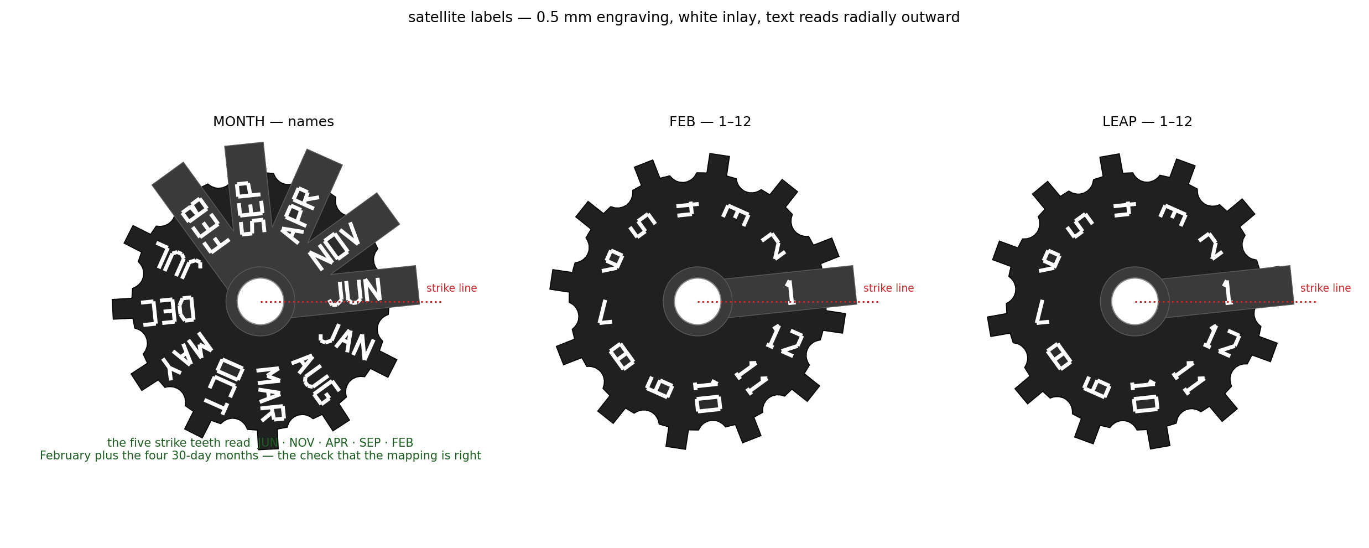
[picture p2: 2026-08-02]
docs/satellite_labels.png

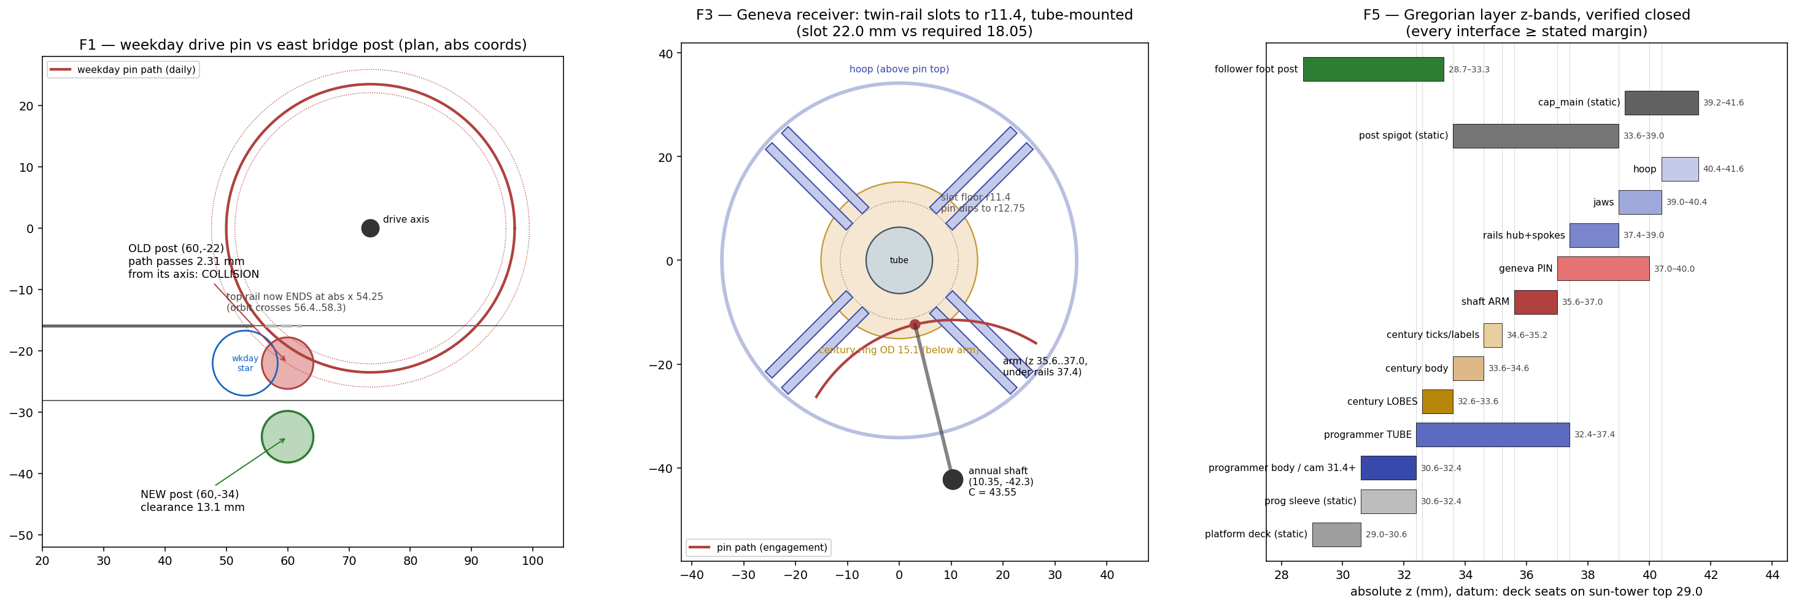
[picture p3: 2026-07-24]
docs/v151-inspection.png

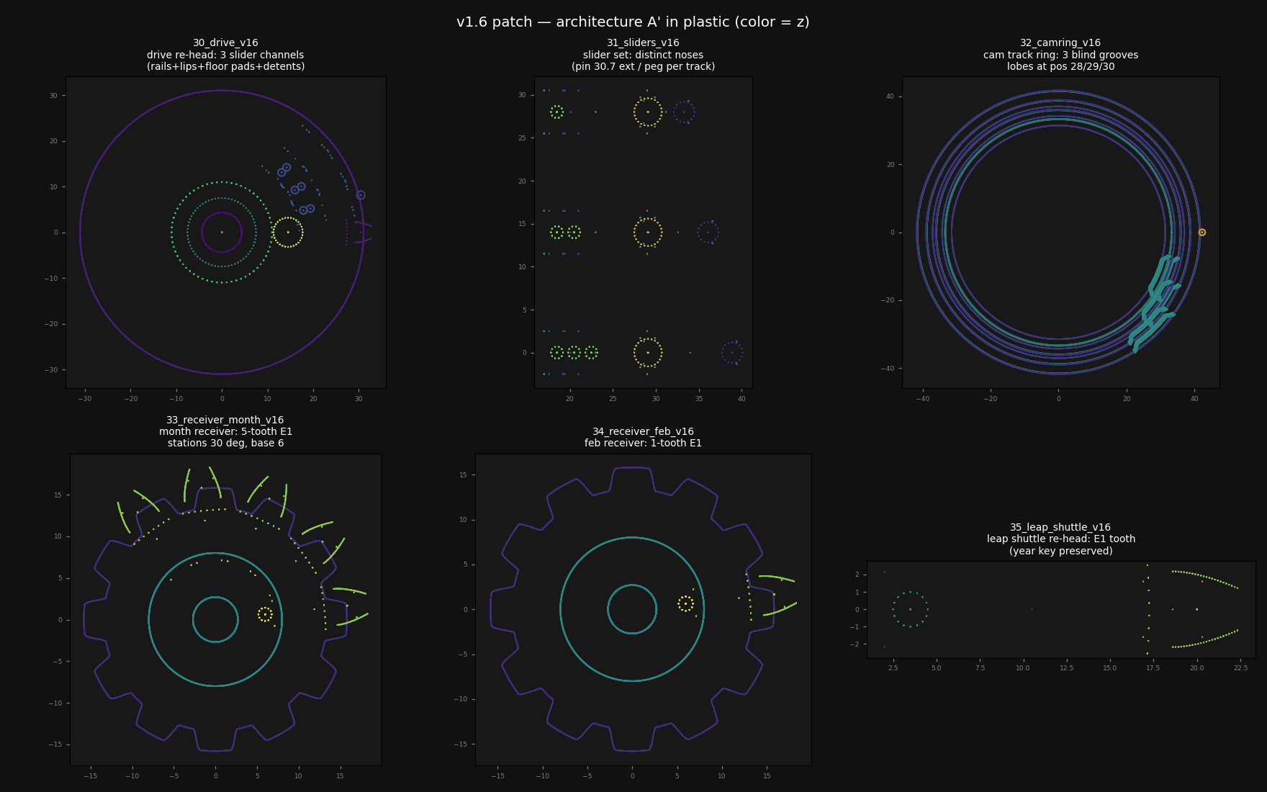
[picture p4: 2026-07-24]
docs/v16-inspection.png

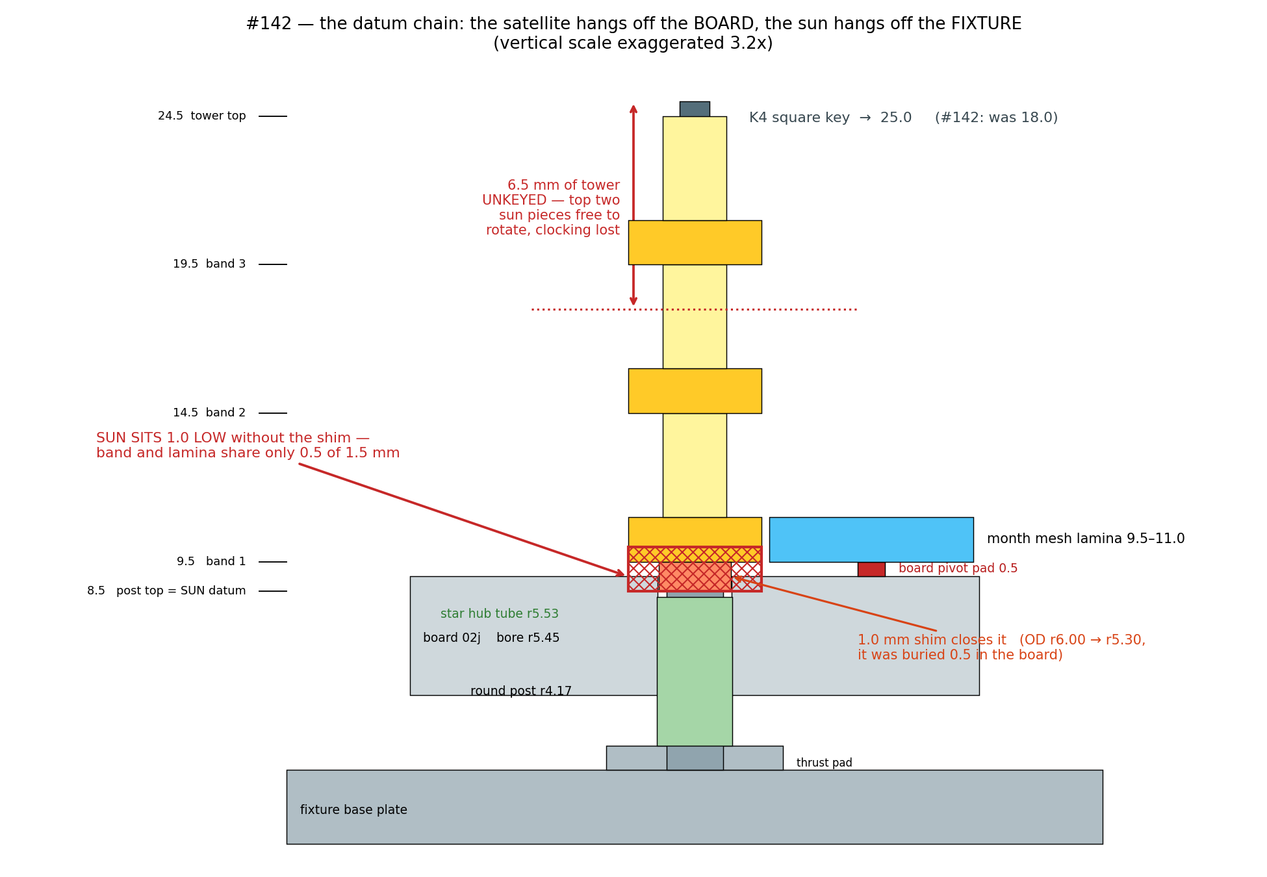
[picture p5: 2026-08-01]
docs/v17_datum_chain.png

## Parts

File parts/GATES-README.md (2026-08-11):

# Running the acceptance gates repo-side

The parts/ generators and gates were authored in the design-office container;
this bundle makes the repo self-contained so they run here too.

## One-time setup
1. `pip3 install numpy shapely trimesh mapbox-earcut manifold3d networkx scipy`
   (user-level install is fine)

   The first three are not sufficient. trimesh needs a triangulation backend or
   every extrude fails with "will not extrude to a volume", and it needs a graph
   engine or `split()` fails with "no graph engines available!". Versions
   verified working repo-side 2026-08-11:

       numpy 2.0.2      shapely 2.0.7    trimesh 4.12.2
       mapbox_earcut    manifold3d       networkx 3.2.1   scipy 1.13.1

   Pin these if byte-stable STLs matter to you — see the epilogue below for why
   they usually do not.
2. `cd parts && ln -sfn stl stl_v13`
   The generators' write_stl() and every gate read/write a directory named
   `stl_v13` next to the scripts; the repo keeps STLs in `parts/stl`. The
   symlink makes them the same place — regenerated STLs land directly in the
   committed tree.

## Support modules (this bundle)
generator.py, generator_v13.py, generator_v16.py, weld.py — the import closure
for every parts/ script. Also two v16 geometry-source STLs the gates slice:
131_month_widesquare_v16.stl (receiver mesh form) and 50e_star_hub_v16.stl
(the retired hub, sliced by board_hub_v17's condemnation gate).

## Gate run order for the #167 commit
1. `python3 fixture_r64_v17.py`   (regenerates 168 + runs the r64 gate, 20 checks)
2. `python3 drive_v17.py`         (regenerates 158-161 + 169, runs the seated-stack
                                   gate incl. rev B condemnation, 10 checks)
Both exit 0 on pass. Regenerated STLs should be byte-stable; if git shows STL
diffs after a run, that is itself a finding — report it, don't commit silently.

Optional full suite: detent_v17.py, detent_accept_v17.py, board_hub_v17.py,
mesh_accept_v17.py, assembly_gate_v17.py.

## Gate-run epilogue (required)

A repo-side gate run is **verification, not authorship**. The committed STLs are
canon: they are the exact bytes the design-office gates measured and the plates
slice, and `gate -> bundle -> repo -> slicer` is the provenance of every printed
part. So after any gate run, check the regenerated STLs against the committed
ones before doing anything else.

For each rewritten STL compare, committed vs regenerated:

| check | pass condition |
|---|---|
| watertight | true before **and** after |
| Δbbox | `0.000000` mm on every bound |
| Δvolume | `< 0.01` mm³ |
| Δarea | negligible alongside the above |

**All pass → environment noise.** Different triangulation backends split the
same polygon into different triangles; triangle counts will move. Run
`git restore parts/stl`, keep the committed bytes, and carry on. No ceremony, no
commit, no log entry — this is expected.

**Any check fails → stop and report.** That is environment-dependent *geometry*,
which is a real finding. Do not commit over it.

Worked example, #167 on 2026-08-11 — all six equivalent, all six restored:

    part                tris          d-volume     d-area      d-bbox
    158_drive_24h       3450 -> 3424  +0.0006 mm3  -0.0019 mm2  0.000000
    159_drive_23h       3306 -> 3280  +0.0013 mm3  -0.0018 mm2  0.000000
    160_drive_22h       3346 -> 3324  +0.0013 mm3  -0.0015 mm2  0.000000
    161_drive_21h       3550 -> 3542  +0.0010 mm3  -0.0006 mm2  0.000000
    168_fixture_r64     1680 -> 1684   0.0000 mm3   0.0000 mm2  0.000000
    169_sleeve_revC     1040 -> 1040   0.0000 mm3   0.0000 mm2  0.000000

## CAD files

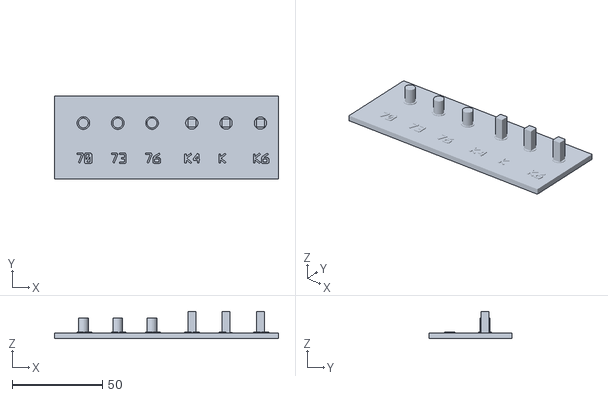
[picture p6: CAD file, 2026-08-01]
parts/stl/135_fullheight_fit_ladder_v16.stl
124.0 x 46.0 x 15.0

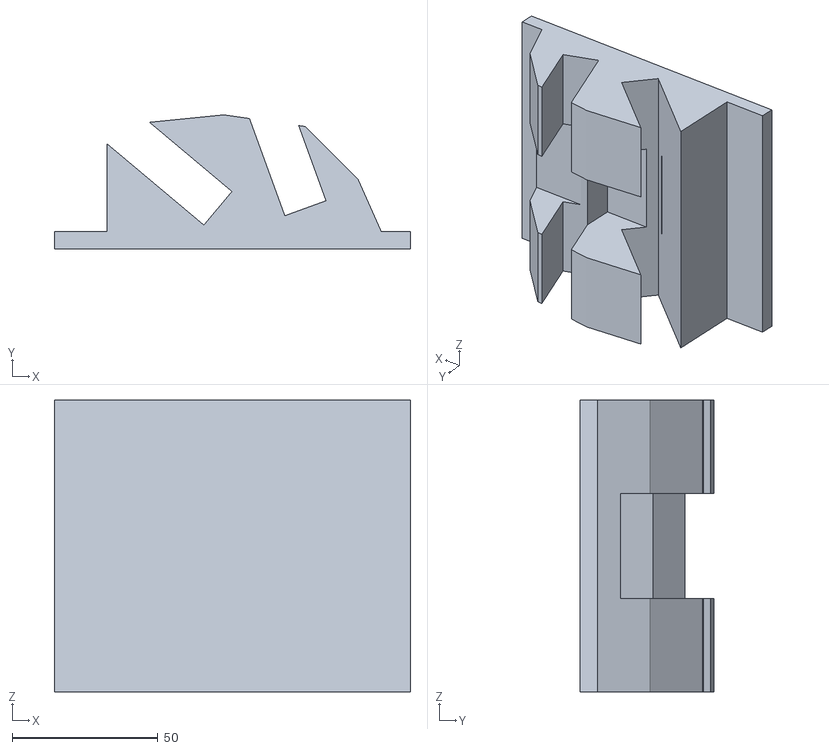
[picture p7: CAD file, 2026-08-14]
parts/stl/180_bench_phone_stand.stl
122.0 x 46.0 x 100.0

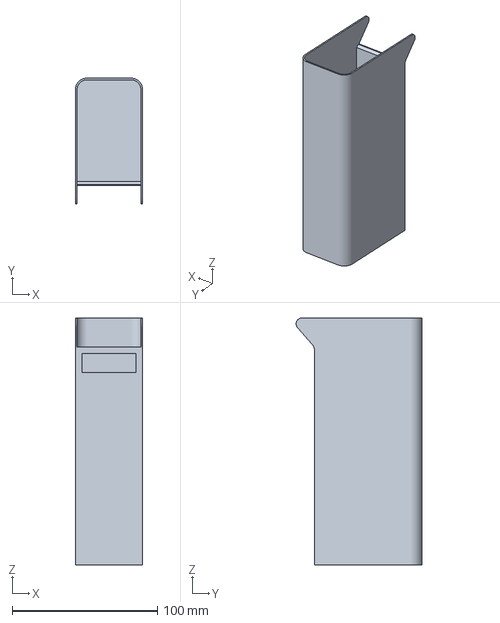
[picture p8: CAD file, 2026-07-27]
poop_chute.3mf
46.3 x 86.6 x 170.0 mm

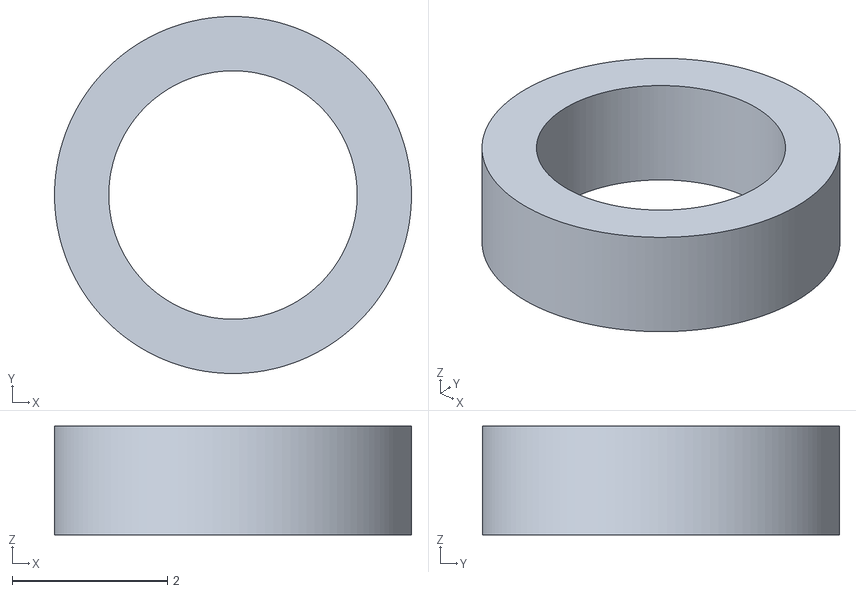
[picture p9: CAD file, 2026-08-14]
parts/stl/177_detent_roller_b32_v18.stl
4.60 x 4.60 x 1.40

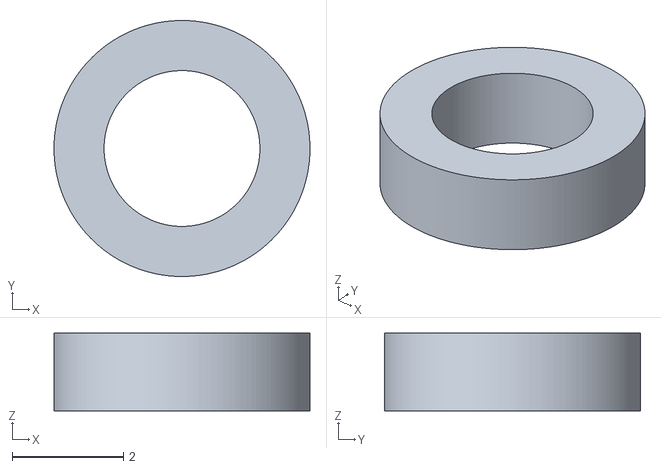
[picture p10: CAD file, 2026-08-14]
parts/stl/177_detent_roller_b28_v18.stl
4.60 x 4.60 x 1.40

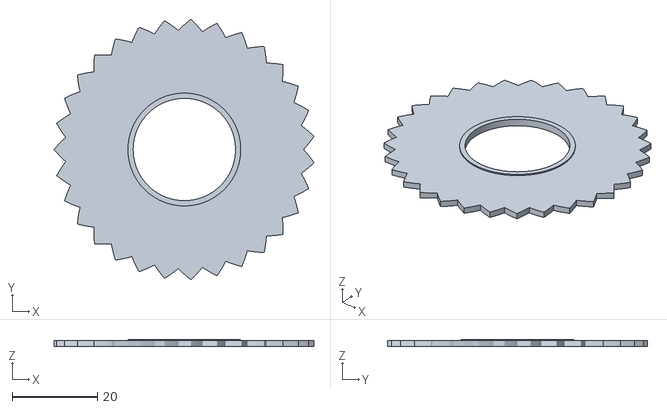
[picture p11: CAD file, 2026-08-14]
parts/stl/175_detent_disc_v18b.stl
60.8 x 60.9 x 1.70

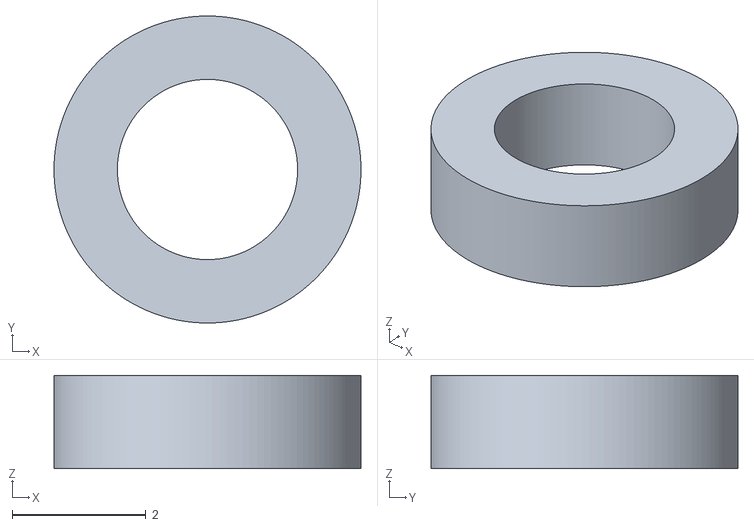
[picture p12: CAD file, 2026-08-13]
parts/stl/177_detent_roller_v18.stl
4.60 x 4.60 x 1.40

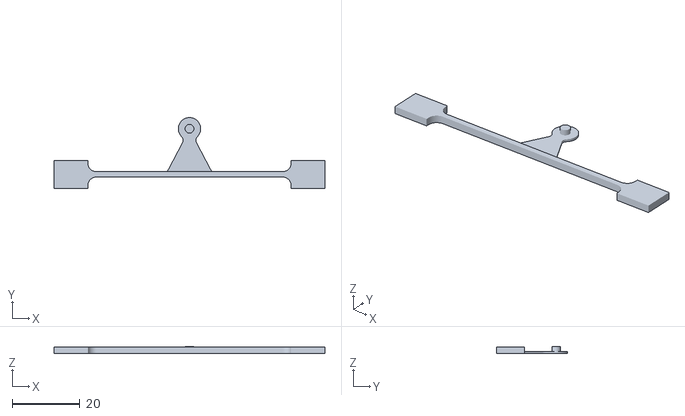
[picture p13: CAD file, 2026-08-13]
parts/stl/176_detent_spring_roller_firm_v18.stl
80.0 x 20.9 x 2.20

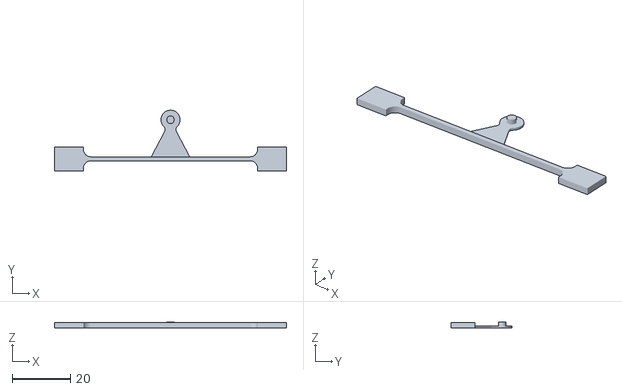
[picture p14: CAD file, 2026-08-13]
parts/stl/176_detent_spring_roller_med_v18.stl
80.0 x 20.9 x 2.20

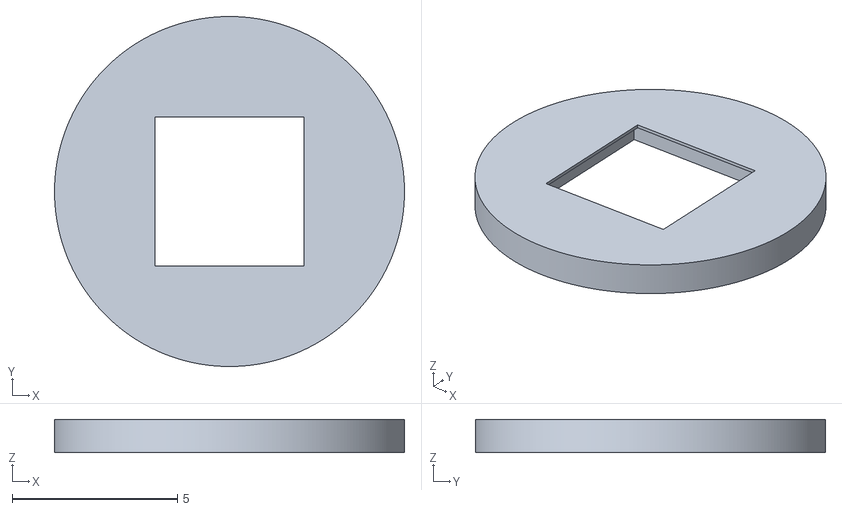
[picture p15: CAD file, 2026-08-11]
parts/stl/172_sun_spacer_revB_v17.stl
10.6 x 10.6 x 1.00

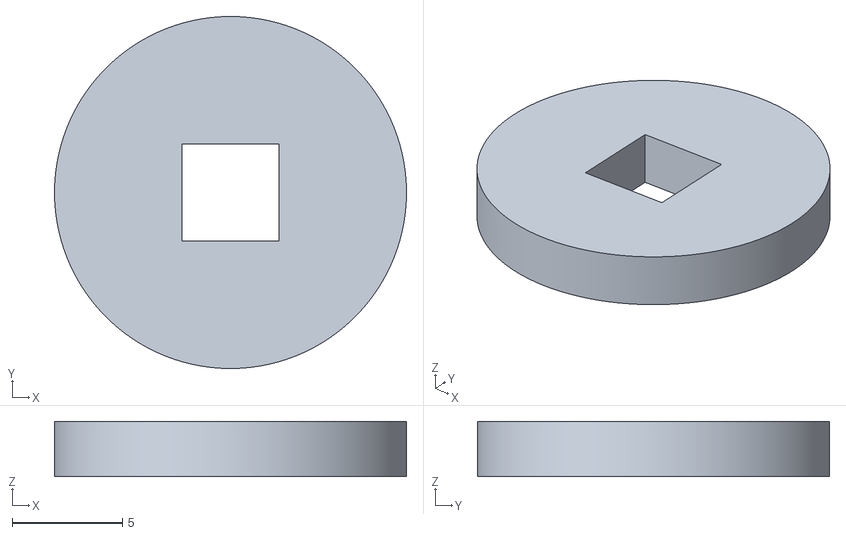
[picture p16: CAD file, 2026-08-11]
parts/stl/170_tower_clamp_cap_v17.stl
16.0 x 16.0 x 2.50

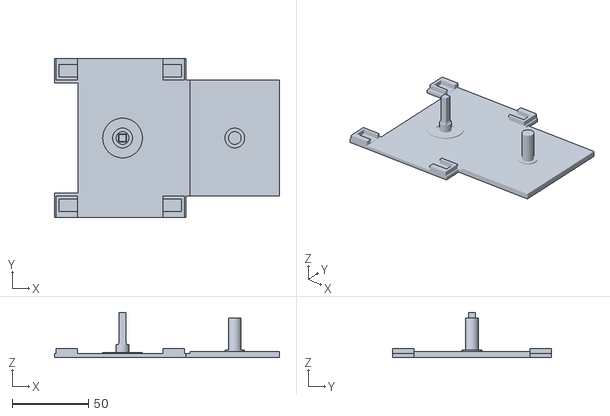
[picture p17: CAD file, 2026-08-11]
parts/stl/171_fixture_r65_v17.stl
147.3 x 104.0 x 29.5

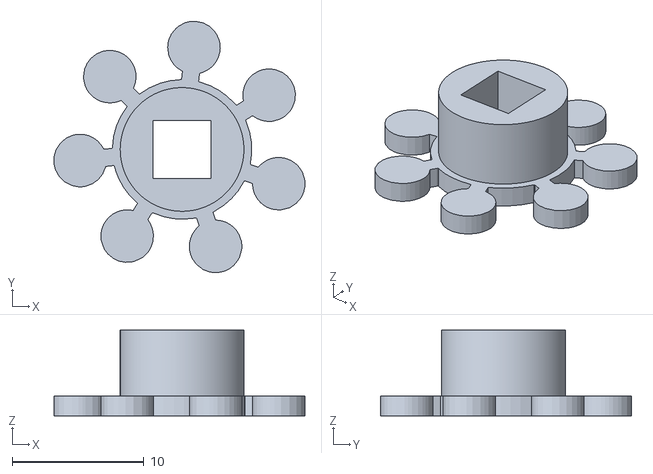
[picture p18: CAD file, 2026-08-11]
parts/stl/174_sun_tower_b440_v17.stl
19.1 x 19.1 x 6.50

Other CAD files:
parts/stl/177_detent_roller_b30_v18.stl
parts/stl/175_detent_disc_v18.stl
parts/stl/176_detent_spring_roller_soft_v18.stl
parts/stl/173_sun_tower_b444_v17.stl
parts/stl/168_fixture_r64_v17.stl
_superseded/49_fixture_r54_v16.stl
_superseded/49_fixture_r57_v16.stl
_superseded/50_detent_star_r4_v16.stl
parts/stl/02_program_wheel.stl
parts/stl/02e_board_bigbore_v16.stl
parts/stl/02f_board_v16.stl
parts/stl/02h_board_v16.stl
parts/stl/113_post_tolerance_coupon_v16.stl
parts/stl/114_central_sleeve_id17_v16.stl
parts/stl/114_central_sleeve_id22_v16.stl
parts/stl/114_central_sleeve_id27_v16.stl
parts/stl/115_meshtest_base_v16.stl
parts/stl/115_meshtest_receiver_inv_v16.stl
parts/stl/115_meshtest_sat12t_inv_v16.stl
parts/stl/115_meshtest_sun7t_inv_v16.stl
parts/stl/115_meshtest_sun_piece_inv_v16.stl
parts/stl/116_meshladder_base_v16.stl
parts/stl/116_meshladder_rec_bl05_v16.stl
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

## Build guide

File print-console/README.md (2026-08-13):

# Print console — Bambu Lab P1S (Oechslin perpetual calendar build)

LAN-mode print console: MQTT status + FTPS upload via `bambulabs_api`,
headless re-slicing via Bambu Studio's CLI.

## Setup

Fill in `.env` with the printer's LAN Mode values (IP, access code, serial).
The venv is already built (`.venv/`, Python 3.12).

## Commands

```
./pc status                      # state, temps, AMS slots, job progress
./pc upload plate.gcode.3mf      # send to printer storage over FTPS
./pc start plate.gcode.3mf --version-tag "plate-01 · v16b"
./pc watch                       # follow active job, layer milestones
./pc reslice project.3mf --xy-compensation -0.05
```

## Standing rules

1. **No print ever starts without an explicit "yes" from Ron in that
   conversation.** `start` prompts interactively; `--yes` exists only for
   after that confirmation has been given.
2. **Read the AMS and show what is in every tray BEFORE asking for that
   yes — every print, without being asked.** Print the tray listing
   (type, sub-brand, colour) alongside the mapping the plate resolves to,
   so the confirmation in rule 1 is given against real filament rather
   than an assumption. `start` derives and validates the mapping itself
   (see `derive_ams_mapping`), but that happens *after* the go-ahead and
   is not visible in advance — the check exists to inform the decision,
   not just to guard the payload. This rule is written because cal-07
   printed a black-specced plate entirely in white: `--ams-slot` defaulted
   to `0`, tray 0 held white PLA Basic, and nothing surfaced the mismatch
   until the parts came off the bed.
3. **Refuse to start when the installed nozzle does not match the plate's.**
   Same class of check as rule 2, and enforced the same way — `cmd_start` calls
   `check_nozzle()`, which compares the sliced 3MF's `nozzle_diameter` against
   the printer's live `nozzle_diameter` and exits rather than starting. Ron now
   runs 0.2, 0.4 and 0.6 nozzles, so a spec's nozzle declaration is load-bearing,
   not documentation. **Every compensation constant in this repo is 0.4-only** —
   `xy_contour_compensation -0.06`, the #136/#137 press arithmetic, the
   0.4-calibrated pocket tabs and roller bores — and none of it may be inherited
   by a plate for another nozzle. A 0.4 plate run on a 0.2 is not just finer;
   its fits are wrong. Deriving the 0.2 and 0.6 constants needs its own
   tolerance-coupon run per nozzle.
4. Every job is appended to `print-log.md` (timestamp · filename ·
   part version · outcome). `watch` records finished/failed outcomes.
5. The access code lives only in `.env` (git-ignored).
6. If the printer is unreachable, commands fail plainly — no silent retries.

## Remote start: firmware unlock (do not re-debug this)

On P1S firmware 01.10.00.00, remote `project_file` start commands over LAN
are **silently dropped** — no error code, state never leaves FINISH/IDLE —
unless BOTH toggles are on at the printer screen:

1. **LAN Only Mode** (Settings → WLAN), and
2. **Developer Mode** (separate Settings entry, visible once LAN mode is on).

Telemetry reads and FTPS uploads work fine either way, which makes the
failure look like a payload bug — it isn't. The working start payload uses
`url: file:///sdcard/<file>`. "Account not logged in" on the screen is the
expected LAN-mode state, not a problem. The access code survives the mode
change.

## Compose pipeline

`./pc compose specs/<plate>.json [--no-stage]` — composes a project 3MF
from STLs + spec (per-part rotate/translate/position, presets, overrides),
slices it, then runs a pre-flight audit on the *sliced* file's embedded
config (machine, process, overrides, plate type, filament) plus a live AMS
check for the required filament. Any mismatch refuses to stage. Preset
configs are generated by the Studio CLI itself and cached in `cache/`.

## Re-slicing notes

- Only saved `.3mf` **project files with embedded presets** are accepted —
  never raw STLs with external config JSONs (the CLI applies external
  presets unreliably).
- `--xy-compensation N` patches `xy_contour_compensation` *inside* a working
  copy of the project's embedded settings, then slices that — the tweak
  always takes effect.
- Slicer: `/Applications/BambuStudio.app/Contents/MacOS/BambuStudio`
  (override with `BAMBU_STUDIO_BIN`), `--mstpp 300` timeout, JSON progress
  via `--pipe`. Output lands in `sliced/`.

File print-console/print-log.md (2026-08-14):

# Print log — Oechslin perpetual calendar demonstrator

Every job: timestamp · filename · part version · outcome.

## Bench-measurements template

Copy per printed plate. Diagnose WHICH dimension ate the clearance before
choosing a fix — `--xy-compensation` is for uniform extrusion swell only;
a local defect gets a local fix or a v16c geometry change.

```
### Bench — <plate> · <version> · <date>
| Dimension          | Spec  | Measured | Δ |
|--------------------|-------|----------|---|
| Channel gap        | 5.4   |          |   |
| Slider width       | 5.0   |          |   |
| Pin                | 3.2   |          |   |
| Peg                | 1.9   |          |   |

Drag notes:
- Slider 1 (21h):
- Slider 2 (22h):
- Slider 3 (23h):
```

- 2026-07-24 13:45 · plate-01-drive-sliders.gcode.3mf · plate-01-drive-sliders · v16b · DID NOT START — printer (fw 01.10) silently drops LAN start commands in cloud mode; file staged on SD, awaiting LAN Mode + Developer Mode enable and a fresh go
- 2026-07-24 13:56 · plate-01-drive-sliders.gcode.3mf · plate-01-drive-sliders · v16b · DID NOT START — LAN Only Mode on, but start command still dropped; Developer Mode toggle still needed
- 2026-07-24 14:27 · plate-01-drive-sliders.gcode.3mf · plate-01-drive-sliders · v16b · DID NOT START — command still dropped after LAN Only Mode enable + job-clear; Developer Mode still off (or unavailable on this UI)
- 2026-07-24 14:41 · plate-01-drive-sliders.gcode.3mf · plate-01-drive-sliders · v16b · DRY RUN, no parts — gcode had no AMS load block (CLI preset merge skips the machine preset's `include` gcode templates → machine_start_gcode was a stub); AMS never fed (tray_now 255). Stopped deliberately at ~76% (error 50348044 = our cancel). Fixed: include-resolution in compose + audit now gates on M620 AMS block in gcode.
- 2026-07-24 15:08 · plate-01-drive-sliders.gcode.3mf · plate-01-drive-sliders · v16b (attempt 2, AMS fix) · FAILED at layer 15/120 — pusher finger detached from bed (Ron observed); stopped deliberately (50348044 = our cancel). Root cause: bed at 45°C on Textured PEI — the CLI preset merge also skips `inherits` chains, so textured_plate_temp fell to a generic 45 default instead of PLA's 55. Fixed: filament inheritance overlay in compose, bed-temp + filament-id audit gates, post-slice identity re-stamp (GFA01) so the printer's AMS RFID check re-arms.
- 2026-07-24 15:27 · plate-01-drive-sliders.gcode.3mf · plate-01-drive-sliders · v16b (attempt 3, bed-temp fix) · FAILED at layer 17 — sliders detached AGAIN, this time at the correct 55°C bed (50348044 = our cancel). Diagnosis: both failures sit at layers 15–17 = the sliders' final layers (sliders top out at z 3.15 ≈ layer 16); tiny footprints (~3×9 mm each) with growing nozzle drag near completion. Local problem → local fix per doctrine; drive wheel unaffected both times. Awaiting Ron's choice of fix (per-object brim / split plates / glue stick).
- 2026-07-24 15:50 · plate-01b-sliders.gcode.3mf · 31_sliders · v16b (solo plate, attempt 1) · started (outcome pending)
- 2026-07-24 15:57 · plate-01b-sliders · FINISHED with a caveat — ran to 100%, but the middle slider detached at ~layer 16/16 (Ron observed); outer two stayed down (solo plate cured the outer-slider problem from combined plates). Pattern across all attempts: sliders only ever detach at their final layers — suspect last-layer detail passes + perimeter bulge from the −0.45 sink knocking small stiff parts. Bench-verdict pending: outers' dimensions + whether the 96%-complete middle slider is usable.
- 2026-07-24 16:25 · plate-01b-sliders.gcode.3mf · 31_sliders · v16b (solo, rev3: supports) · started (outcome pending)
- 2026-07-24 16:34 · plate-01b-sliders · finished OK — rev3 (solo + plate-only supports + slow finish) ran all 17 layers clean; Ron: parts look great after support removal. First good sliders of the build. Caliper numbers → bench template above when taken.
- 2026-07-24 17:32 · plate-01a-drive.gcode.3mf · 30_drive · v16b (solo, crank grip deferred) · started (outcome pending)
- 2026-07-24 17:58 · plate-01a-drive · finished OK
- 2026-07-24 20:34 · plate-01c-sliders-pegs.gcode.3mf · 31_sliders + 37_peg_pins · v16c (flat, finding-44 fix) · started (outcome pending)
- 2026-07-24 20:44 · plate-01c-sliders-pegs · finished OK — v16c flat-print run: all 14 layers, zero interventions, no supports, no detachments. Finding-44 categorical fix validated at the printer. Bench next: peg press-fit into sliders, slider drag in drive channels, caliper numbers → template.
- 2026-07-25 · BENCH · channel rail break on 30_drive during slider fitting (finding #46) — CA-repaired and serviceable; v16d rail reinforcement pending in a future drive re-emit.
- 2026-07-25 · BENCH · hub crank breakage on 30_drive — 38_crank_module_v16 (press-on crank module) is the field repair; prints disc-down, no source in generator_v16.py (hand-authored).
- 2026-07-25 05:58 · plate-01d-v16d.gcode.3mf · v16d plate (sliders + pins + crank module) · started (outcome pending)
- 2026-07-25 · BENCH · sliders have poor sliding motion, and lose alignment as they extend — nothing guides the outboard end once the plate leaves the rails (Ron). Mesh analysis of the v16fullset wheel: changes are rail reinforcement + near-hub ring only (all within r≈29; rim at 32.8) — NO outboard guidance added; the failure mode is not addressed in the staged geometry. Needs a design-office fix (rim-side capture/guide); v16d generator still not delivered.
- 2026-07-25 06:20 · plate-01d-v16d · finished OK, then SUPERSEDED — ran to 100% (105 layers, clean) before the v16d full-set drop landed; parts are from the interim generation. Superseded by plate-02-v16d-set (reinforced-rail wheel + revised 31/37/38).
- 2026-07-25 09:16 · plate-03-camring.gcode.3mf · 32_camring · v16 (outboard guide) · started (outcome pending)
- 2026-07-25 09:28 · plate-03-camring · finished OK
- 2026-07-25 10:24 · plate-02-v16d-set.gcode.3mf · v16d full set + seat markers · started (outcome pending)
- 2026-07-25 · BENCH · finding #48: middle-channel obstruction and slop — root-caused to fan self-intersection in the channel architecture; fixed in v16e (outboard furniture, bisector wedges, gate A14). v16e r1 shipped with a degrees/radians emission bug (edge rails/lips/wedges axis-aligned; the 21h outboard lip orphaned mid-air) — caught by the console's mid-air gate, the only working detector in the pipeline that day (design office skipped its own A10 census); fixed in r2 (finding #49).
- 2026-07-25 · BENCH · over-travel note for future sessions: the slider's working envelope is the span between the two friction-dome marks; the travel STOP is the cam groove by design — an unmounted slider is a free body and will happily slide out of the channel. Not a defect; assemble the camring before judging travel.
- 2026-07-25 11:05 · plate-02-v16d-set · finished OK — full v16d set in one clean run (105 layers, no interventions): reinforced-rail wheel with seat-indicator bars, revised flat sliders, drop-in pins, spare crank module. Third consecutive zero-intervention print. Bench: full subsystem assembly with camring.
- 2026-07-25 12:26 · plate-03-wheel-camring.gcode.3mf · 30_drive v16e r2 + 32_camring (findings 48-49) · started (outcome pending)
- 2026-07-25 12:58 · plate-03-wheel-camring · finished OK — v16e r2 wheel (fan fix, outboard furniture, bisector wedges) + camring in one clean run, 75 layers, fourth consecutive zero-intervention print. Known caveat carried: camring middle-track thin rings start at layer 2 (slicer min-feature; identical to the already-benched ring). Bench: full finding-48 subsystem — v16e wheel + ring + v16d sliders/pins.
- 2026-07-25 13:31 · plate-04-fixture-carrier.gcode.3mf · 39_bench_fixture + 40_ring_carrier (bench tooling) · started (outcome pending)
- 2026-07-25 14:45 · plate-04-fixture-carrier · finished OK — bench fixture + ring carrier, 120 layers, fifth consecutive zero-intervention print. Bench tooling complete: fixture gives true axis spacing, carrier seats the camring at board-top height (also moots the ring's layer-1 caveat in use). Full v16e subsystem + tooling now printed.
- 2026-07-25 16:11 · plate-06-v16f.gcode.3mf · v16f detent mount: camring + pins +0.45 + files7 wheel (finding 55) · FAILED at layer 29/75 — camring spaghettied (Ron observed, camera-confirmed); stopped deliberately (50348044 = our cancel). Root cause: the clocking spider's ~24mm bridges at 0.55mm altitude — too low to sag-and-catch; strands dragged and destroyed the ring. The flagged bridge risk should have been a stop-and-tell, not a caveat (console doctrine updated). SALVAGE: 8 pins complete (they finish by ~layer 16) — harvest; wheel was cleanly formed at stop but incomplete. Finding for design office: the v16f spider needs a printable foundation — ≥3mm bridge altitude, legs under arm midpoints, or emit the spider as a separate flat jig.
- 2026-07-25 16:56 · plate-06a-v16f-nospider.gcode.3mf · v16f ring (spider dropped) + files7 wheel · finding 55 reprint · started (outcome pending)
- 2026-07-25 17:28 · plate-06a-v16f-nospider · ran to 100% but MIXED — wheel correct (Ron confirmed); camring spaghettied AGAIN despite spider removal. Root cause #2: the ring body overhangs the 31-segment skirt band circumferentially (inner 2.6mm / outer 4.5mm cantilevers at 0.55mm altitude) — unsupported perimeter loops droop and drag. The v16f detent architecture cannot print bare; needs a raft (or design-office wall-footed skirt). Wheel harvested.
- 2026-07-25 17:39 · plate-06b-camring-raft.gcode.3mf · 32_camring v16f solo on raft (finding 55, attempt 3) · started (outcome pending)
- 2026-07-25 · plate-07: architecture audition — patent-literal fixed fingers (v1.3) vs cam-gated sliders (v16), comparative bench trial; day-30 cross-talk is the predicted failure mode to watch for. Audit result: 02_program_wheel + 04_month_wheel clean and staged; 10_drive_wheel NOT stageable — emitted pin-down (drive pin is the lowest geometry, functional), and flipped per the v1 README its disconnected crank post (the ancestral finding-45 gap) becomes the bed contact with the body hovering 10mm. Fix path if wanted: flip + drop post + overhang fingers.
- 2026-07-25 17:54 · plate-06b-camring-raft · finished OK — v16f detent ring printed intact on the third attempt (solo + raft + spider dropped); camera shows a clean annulus, no spaghetti. The v16f skirt architecture requires a raft until the design office ships wall-footed skirt geometry (finding logged). Bench: peel raft, check detent feet, snap onto board tick bumps.
- 2026-07-25 18:42 · plate-07-audition.gcode.3mf · v1.3 audition: program wheel + month receiver (fixed-finger trial) · started (outcome pending)
- 2026-07-25 19:23 · plate-07-audition · finished OK — v1.3 program wheel (31 rim teeth verified in toolpaths) + month receiver, all 62 layers clean. Audition bench: fixed-finger trial vs v16 sliders; check the board top face for tick bumps (mesh says absent → v16f ring detent-mount compatibility question); 10_drive_wheel still held pending flip+post-drop surgery (plate-07b on request).
- 2026-07-25 · BENCH · Arm A assembled: v1.3 board + fixed-finger drive wheel meshed on the fixture; daily advance functional; full 31-position referendum crank in progress.
- 2026-07-25 · BENCH · Finding #56: the v16f spider's 0.55 mm bridge altitude — unprintable as emitted (two spaghetti failures); the console's field drop of the spider was correct. Design office owes a printable spider foundation (≥3 mm bridge altitude, mid-arm legs, or separate flat jig).
- 2026-07-25 · BENCH · Finding #57: the ring carrier's rim intrudes the daily tooth's swept circle — carrier retired from meshed service.
- 2026-07-25 · BENCH · Finding #58: the drive wheel's witness dot (0.8 proud, near the 23h arm) grazes the board's tooth tips at mesh — no mechanical function, shaved flush at the bench. Design office owes: markers relocated out of the mesh overlap band + a marker-clearance gate in the next wheel emission.
- 2026-07-25 · BENCH · Finding #59: stale-STL vintage mismatch — the audition board (stl_v13 emission) is bumpless: it predates the tick-bump code in the current generator source (console audit caught this pre-print). Arm A unaffected (rim teeth + satellite post present); Arm B's v16f detent ring indexes on those bumps. Doctrine: audition prints on trust are fine, but any part entering a fit-critical interface gets regenerated from current source and gated first.
- QUEUE (pending referendum verdict — if Arm A sweeps its 31 positions, next plates may be a different architecture entirely): v16f-r2 ring (raised plane, real key cavity, printable spider foundation per the ≥3 mm spec); #58-clean wheel emission (markers out of the mesh overlap band + marker-clearance gate); fresh 02_program_wheel regeneration from current source with the full gauntlet (finding #59) — REQUIRED before any Arm B session unless Ron confirms the originally-printed board carries the bump circle and tall pos-1 witness on its face.
- 2026-07-25 20:56 · plate-08-crank.gcode.3mf · 38_crank_module spare (referendum bench) · started (outcome pending)
- 2026-07-25 21:14 · plate-08-crank · finished OK
- 2026-07-25 21:28 · plate-07b-jumper.gcode.3mf · 12_jumper v1.3 flexure (audition pair) · started (outcome pending)
- 2026-07-25 21:36 · plate-07b-jumper · finished OK
- 2026-07-26 05:53 · plate-09-fixture-r2-arm-a.gcode.3mf · fixture r2 + Arm A hardware (surgical wheel, jumper, sun tower) · started (outcome pending)
- 2026-07-26 07:39 · plate-09-fixture-r2-arm-a · finished OK — all 138 layers: fixture r2 (sun key, shoulder, jumper wing), surgical drive wheel (no pin/post), spare jumper, sun tower. Arm A moves to real tooling.
- 2026-07-26 · BENCH · Finding #63 CLOSED + wobble doctrine: receiver rides spacer 43 above the tick bumps; gravity-seated for the audition (planar loads only — adequate); cap_sat is the designed retention, queued (inspected: one-piece, consistent winding, spigot bore open in toolpaths — render-verified).
- 2026-07-26 09:10 · plate-10-referendum-set.gcode.3mf · referendum set: fixture r4 + jumper + sun + spacer (findings 60-64) · STOPPED at layer 0 on Ron's order, still in warm-up — no material laid; file remains staged on SD for a clean restart.
- 2026-07-26 09:28 · plate-10b-referendum-set.gcode.3mf · referendum set + board (findings 60-64) · started (outcome pending)
- 2026-07-26 · DESIGN BACKUP · rotational-gear jumper (Ron): rotary positive indexing in place of the flexure — ancestors in the notes: patent Geneva-lock (patent-review.md L28), v1 springless locking-disc, and skip-redesign-session2 option (B). Constraint any rotary design must satisfy: disengage/freewheel during month-end 1-4 step cascades (the recorded reason the rigid lock was retired for the flexure). Held as backup if the PLA/PETG flexure fatigues in referendum service.
- 2026-07-26 11:03 · plate-10b-referendum-set · finished OK — all 120 layers: fixture r4, v1.3 board, open-bore jumper, square-bore sun, receiver spacer. Thermal doctrine ran live (215C body). The referendum endgame kit is printed.
- 2026-07-26 · DOCTRINE · finding 69: gear pairs are matched-vintage sets; stale receiver vs current sun = interference; meshing parts regenerate together henceforth. First application: 33_receiver_month regenerated from the files13 generator — byte-identical to the repo copy, vintage-match confirmed by regeneration rather than trust.
- 2026-07-26 · Finding #70: 33_receiver_month's witness dot floats 1.6mm above the hub top (anchored at a stale height since the original emission; ray-parity verified). Field drop for plate-11 — mark station k=0 by hand per the clocking table; design office owes a re-anchored dot.

- 2026-07-26 12:28 · plate-11-jumper6-receiver.gcode.3mf · jumper v6 + receiver (findings 67-70) · started (outcome pending)
- 2026-07-26 12:48 · plate-11-jumper6-receiver · finished OK — all 40 layers: jumper v6 (long-spring rounded beak) + receiver (dot dropped, mark station k=0 by hand). The current program is fully printed.
- 2026-07-26 · SESSION TAIL · Finding #70 (broadened; supersedes the narrower floating-dot entry above): v16 receiver fingers unrooted — features anchored at stale heights; design office owes 33 r2 next session. Findings #71–73: jumper beak iterations (long-spring V, rounded beak, culminating in Ron's rod-and-ball with the head bench-gauged to r4.4 against the actual board teeth). DOCTRINE reminder: matched-vintage pairs only — tonight's stack runs the v1.3 sun + receiver together.

- 2026-07-26 14:17 · plate-12-jumper-v9.gcode.3mf · jumper v9: rod-and-ball, bench-gauged head (findings 72-73) · started (outcome pending)
- 2026-07-26 14:27 · plate-12-jumper-v9 · finished OK — all 18 layers: rod-and-ball jumper, bench-gauged r4.4 head (findings 72-73). Ninth jumper iteration, first designed at the bench.
- 2026-07-26 · finding 74: bearing sleeves (44_post_sleeves) — mesh clearance stack; verified grounded, queued as plate-13 solo (~5 min).
- 2026-07-26 · CLEANUP LIST (next session): (1) generator carries a harmless duplicate acceptance_43 definition from an earlier edit — deduplicate; (2) receiver r2 (finding #70: re-rooted fingers + re-anchored witness dot).
- 2026-07-26 · SESSION TAIL · Finding #74: bearing clearance stack → post sleeves. Finding #75: jumper reach — head center pulled 1.25mm deeper (44.5 from board axis) to seat in the valley instead of grazing tips; rod 1.3→1.8 for real preload. Sleeve-first doctrine: fix the datum before tuning the instrument. BENCH STATE: v9 installed and tip-riding pre-sleeve; v10 is the post-sleeve contingency; matched v1.3 sun+receiver pair staged for the referendum; receiver 33 r2 and the duplicate acceptance_43 cleanup are the design office's openers next session.

- 2026-07-26 14:54 · plate-13-jumper10-sleeves.gcode.3mf · jumper v10 + post sleeves (findings 74-75) · started (outcome pending)
- 2026-07-26 15:09 · plate-13-jumper10-sleeves · finished OK — all 63 layers: jumper v10 (seating reach, 1.8 rod) + six-sleeve fit ladder. Sleeve-first doctrine ready to run at the bench.
- 2026-07-27 · HOUSEKEEPING · findings 74–86 record:
  · #74 bearing clearance stack (0.85 mm) → sleeve ladder → fitted; sleeves now being absorbed into bore lands, part 44 retires.
  · #80 the v1.3 sun cannot key on the r4 square post (1.31 mm gap) — matched gears isn't enough, the sun must match the post.
  · #83 the detent arm sees compression in reverse; taller-and-narrower section fixes buckling and cuts fwd/rev asymmetry 14% → 2%.
  · #85 WITHDRAWN — a Geneva locking disc was claimed; there is none.
  · #86 the drive wheel body clears the board tips by 2.44 mm by design — a rigid lock would block the month-end cascade, so the jumper is the machine's sole index. The plate-09 mid-air drop was correct: the amputated pin was the WEEKDAY pin, not the daily driver — the daily tooth is present and working. Do not drill the wheel; part 48 is withdrawn (archived in parts/stl for the record).
- 2026-07-27 · Repo sync notes: 02_program_wheel current-source verified (31 tick bumps + tall pos-1 witness in mesh census — finding #59 satisfied); 44 unchanged (already current); 42_sun r2 "full column" NOT yet landed (repo copy is yesterday's — awaiting drop); generator not in this drop (files17 copy stands). Printability flags for future plates: 45 and 46 carry small mid-air features (borderline heuristic; re-check at compose time).
- NEXT SESSION plate: detent star ring, roller + pin, fixture r5 (pocket, anchor, mid-span guide), arm r3, receiver 33 r2.
- 2026-07-27 · sun r2 full column landed (10.00mm verified — the wafer tripwire caught nothing this time) + current generator (gates through A36; the duplicate acceptance_43 persists — cleanup item stands). Parts 45 (wire jumper holder) and 46 (wedge set) are SUPERSEDED — the wire branch of the detent lost to the printed arm with the cam adjuster; their mid-air printability flags need no action; archived in parts/stl alongside withdrawn part 48. Nothing composes today; next session's plate stands as recorded.
- 2026-07-27 · SESSION CLOSE · Finding #87: vintage verified by GEOMETRY, not metadata — the byte-identical-size sun proved only a height check could tell wafer from column; the doctrine generalizes (md5 and file size are hints; the gauge is the truth). The detent set arrives as the machine's sole index per #86. BENCH assembly order for the record: plate → arm on pins → cam → ring flat-face-up on the shelf → drop-in pin through the outrigger → board onto the collar with the pin in a rim valley → wheel, phase, crank.

- 2026-07-27 12:14 · plate-14-index-set.gcode.3mf · index plate: basin fixture r5 + detent star + arm r3 (findings 82-87) · started (outcome pending)
- 2026-07-27 13:22 · plate-14-index-set · finished OK — all 120 layers: basin fixture r5, 31-spike detent star, arm r3. The machine's sole index (per finding 86) is printed.
- 2026-07-27 · Finding #96 (against the design office): the shipped v1 qc_sweep and the tool that produced the 'clean' verdict were different programs — the corrected manifest lived only in a session. The vintage disease (#59, #87) infecting QC tooling itself: THE GATE IN THE REPO MUST BE THE GATE THAT CLEARED THE PLATE. v2 lands with assembly placement, sub-part isolation, flush tolerance 0.12, and the star↔arm + seat whitelists. Shakedown record: six real catches this session (findings 88, 89, 91's island, 92, 95, and 96 itself); two before any plastic moved. Console triage of the five v1 hits confirmed correct; item 5 dissolved as the cam-at-print-position striking the amputated weekday pin — a phantom on a phantom. DOCTRINE residue: multi-part STLs get per-sub-part manifest entries, and swept envelopes model the part AS-PRINTED.
- STANDING RULE: qc_sweep runs before every compose; any unwhitelisted VIOLATION is stop-and-tell, same authority as the mid-air check.

- 2026-07-27 14:52 · plate-16-index-corrected.gcode.3mf · index plate corrected (findings 88-96) · started (outcome pending)

- 2026-07-28 · DESIGN OFFICE · NEXT SESSION plate: plate-17 flag-free detent set (findings 97–99 + coupling redesign). PARTS: 02e_board_bigbore + 50d_star_hub + 49_fixture_r57 + 51_bridge_arm. The bridge jumper (finding #99) is the machine's sole index — a pinned-pinned flexure carrying a POINTED, both-flank-bearing wedge into a full-depth 31-notch star. Notch kept at 2.5 mm deep; the WEDGE was shortened + pointed (not the notch, per Ron). Star is now a plain scallop disc with a CENTRAL PRESS-TUBE (flag/outrigger killed) that rides the program post and press-fits the board's enlarged bore; fixture collar → central thrust pad. Bridge moved in to r30.5 (short riser, less twist) with both pin bores OPEN top-to-bottom (finding 64/93 clear). Gate: qc_sweep_central.py → CLEAN. All 4 watertight (0 open edges); all acceptance gates pass.
  · PRINT: all four FLAT, NO supports — board teeth-up, star scallop-down (tube rises), fixture flat, bridge flat (in-plane flexure).
  · CHANGED PART: 02e board — central bore enlarged 8.7 → 10.9 for the press-tube; RE-PRINT required (teeth / day-ticks / month post unchanged). The other three are new parts that drop in.
  · BENCH (first assembly): (1) star central tube → board bore is a designed interference press — tune on first fit; (2) bridge pins → anchor bores likewise; (3) wedge drops into each notch with a clear click and self-centers on both flanks — verify no twist across the 31-position sweep; (4) star disc spins free on the thrust pad, board seats on the disc top.
  · ALSO IN REPO: 33_receiver_month_r2 (finding #70, re-anchored witness) — available, independent of this plate.
  · Superseded parts moved to _superseded/ (49_fixture_r54, 50_detent_star_r4, emit_bridge99, qc_sweep_bridge). Regenerate the whole set from parts/emit_final.py.
  · Awaiting Ron's "yes" to compose/print (standing rule 1).
- 2026-07-28 · Finding #100 (against the design office, doctrine #96 recurrence): the shipped qc_sweep_central.py `load()` searched only `stl_v13/` and `./` — from the repo root it found ZERO of the six parts, printed a vacuous 'RESULT: CLEAN' over an empty set, then crashed (NoneType, exit 1) on the trailing star check. A gate that clears nothing is not a gate. Console verified the geometry IS clean by running the UNMODIFIED script in a scratch dir where its paths resolved (all six load, CLEAN, exit 0) — tooling defect, not interference. FIX: path list now ('parts/stl/','parts/stl_v13/','stl_v13/','') so the gate clears from repo root like test_plate17_flagfree.py does. Re-run: genuine CLEAN, all six loaded, exit 0. The gate in the repo is once again the gate that clears the plate.

- 2026-07-28 11:53 · plate-17-flagfree-detent.gcode.3mf · flag-free detent: 02e board + 50d star + 49 fixture r57 + 51 bridge (findings 97-100) · started (outcome pending)
- 2026-07-28 13:28 · plate-17-flagfree-detent · finished OK — all 120 layers: 02e big-bore board, 50d star hub, fixture r57, bridge jumper. Machine's sole index printed; both gates cleared (central sweep after finding-100 path fix). Bench: two press fits (star tube->board bore, bridge pins->anchor bores), wedge into 31-notch star.

- 2026-07-28 · DESIGN OFFICE · Finding #101 (Ron caught, on the printed plate): the program post on fixture r5.7 FLOATED. When the flag was killed and the island shelf became the thrust pad, the post lost its root — it started at z4.0 but the base slab ends at z2.5 and the thrust pad is an annulus at r6.5 that never touches the post. It printed in mid-air (the whisker nest) → no post for the board/star to mount to. NONE of the gates caught it: watertight sees a closed cylinder, qc sees no interference, the slice audit checks per-object first-layer, not a floating sub-feature. FIX: fixture r5.8 — program post rooted to the slab (z2.5→9.5). NEW GATE: test_plate17_flagfree.py now has a [4] base-connectivity check (even-odd occupancy up each post axis) that flags any feature not continuously solid to the bed — it FAILs r5.7, PASSes r5.8. Full gate ALL PASS on r5.8; interference CLEAN.
  · REPRINT: FIXTURE ONLY — 49_fixture_r58. The board (02e), star (50d), bridge (51) from plate-17 printed clean and are UNAFFECTED (the board's own satellite post is rooted; its whiskers were ooze, not a float). Compose a fixture-only plate, or re-run the full spec (now r5.8).
  · PRINT NOTE: the tall lone posts string from nozzle ooze on long travels — cosmetic, cleans off. For the reprint a wipe/prime tower or a couple °C lower nozzle + more retraction cuts it.
  · specs/plate-17-flagfree-detent.json, qc_sweep_central.py, README.md updated r5.7→r5.8; 49_fixture_r57 moved to _superseded/.
  · Awaiting Ron's "yes" to compose/print the fixture reprint (standing rule 1).
- 2026-07-28 15:07 · plate-17b-fixture-r58.gcode.3mf · fixture r58 reprint: program post rooted (finding 101 fix) · started (outcome pending)
- 2026-07-28 16:05 · plate-17b-fixture-r58 · finished OK — all 120 layers: fixture r58 with the program post ROOTED to the slab (finding 101 fix). Anti-string tweaks (retract 1.6, 210C). Flag-free detent now complete in hand: press star tube->board bore, bridge pins->anchor bores, wedge into 31-notch star.

- 2026-07-28 · DESIGN OFFICE · Finding #102 (Ron's question, verified by sweep): "do the pegs block the gears?" — YES, three of them. The engine interference sweep (parts/engine_sweep.py) models each satellite as a DISC about its board-fixed pivot (the satellites are fixed to the board and only spin — a full annulus was too conservative and self-flagged the pivot post; corrected). Assembly Z-truth from the seating gates: board top z9.0, sun z9.5-19.5, month mesh lamina underside z10.4 (board top + finding-63 spacer 1.4). On board 02e the 30 short day-ticks (h1.0, top z10.0) clear by 0.4mm, but the TALL pos-1 peg (h2.2, top z11.2) pokes +0.8mm and station dots M/F (h1.6, top z10.6) poke +0.2mm up INTO the month mesh lamina — a real skim on every pass. Board 02f removes all 31 pegs + 3 dots -> zero raised obstacles except the pivot post -> sweep CLEAR. feb/leap ride at z>=13, above every obstacle top (11.2), never at issue. FRAME SELF-CHECK (guards the finding-96/100 vacuous-pass disease): the assembled sun (r11.25, z9.5-19.5) must and does overlap the month mesh lamina in r and z -> MESH CONFIRMED before any 'clear' is trusted. Sun tower verdict: correctly configured (finding-79 full keyed column holds in-frame). Both boards watertight (0 open edges). 02f UNCHANGED vs 02e except the two removed feature loops (involute rim, 10.9 bore, month post + D-key intact) -> flag-free press-fit unaffected.
  · REPRINT: BOARD ONLY — 02f_board_v16. The star (50d), fixture (49 r58), bridge (51) are unaffected and stay as printed. specs/plate-18-board-02f.json ready (board teeth-up, flat, no supports). New gate parts/engine_sweep.py in repo.
  · Awaiting Ron's "yes" to compose/print plate-18 (standing rule 1).

- 2026-07-28 · DESIGN OFFICE · Finding #103 (naming clarified, no geometry change): Ron asked whether the 24h wheel needs re-drafting so "Feb-28 hits first in CW." Verified against the authoritative sim (docs/feb-eom-forensic.log) + the cam schedule: it ALREADY does, structurally. Strike order in a cascade is set by the camring lobe map LOBEPOS={21:28, 22:29, 23:30}, NOT the arm angles — in CW/forward the board reaches pos 28 before 29/30, so the pos-28 slider fires first (log opens with ovl=[L21] at pos=28, 20:30, before M23 at pos=31 ~23:15; FWD summary: no jam). NAMING TRAP: the arm doing the common-Feb (28-day) skip is the 21h/L21, and the 22h/F22 arm does the leap-Feb (29-day) skip — i.e. the brief's "22h=feb / 21h=leap" labels read backwards vs the plain feb=28 / leap=29 convention. Functional truth: 23h=month (30 vs 31, pos 30), 22h=leap-Feb (pos 29), 21h=common-Feb (pos 28). Ron reviewed the evidence and chose NO redraw — the wheel is correct; this is a labeling note only. part_30_drive_v16 and the camring stand unchanged.

- 2026-07-28 · DESIGN OFFICE · plate-18 AUTHORIZED by Ron (this session) — board 02f reprint (finding #102). BOARD ONLY; star 50d / fixture 49 r58 / bridge 51 are unaffected and stay as printed. Gate: 02f watertight (0 edges) + engine_sweep.py CLEAR (docs/engine-clearance-sweep.md). Spec: specs/plate-18-board-02f.json (teeth-up, flat, no supports, black PLA Matte, anti-string overrides). Handed to Claude Code to compose → pre-flight audit → start → watch → log outcome.
- 2026-07-28 18:26 · plate-18-board-02f.gcode.3mf · plate-18 · board 02f (pegless, finding 102) · started (outcome pending)
- 2026-07-28 19:31 · plate-18-board-02f · finished OK — all 62 layers: board 02f (31 day-tick pegs + 3 station witness dots removed, finding 102). Watertight PASS, engine clearance CLEAR (02e had +0.8mm day-1-peg grind into the month lamina). Anti-string tweaks (retract 1.6, 210C). Completes the flag-free detent stack: board 02f + star 50d + fixture r58 + bridge 51.

- 2026-07-28 · DESIGN OFFICE · FULL ENGINE CAMPAIGN authorized by Ron ("print the rest of the calendar gearing"; scope = full current-rev engine set; gate = full engine sweep first). GATE GREEN (docs/engine-gate.md): all 14 engine parts watertight (0 open edges); board-02f engine sweep CLEAR (frame self-checked vs sun<->month mesh); ALL engine acceptance gates PASS (drive/sliders/camring A2-A14, sun A31 band coverage = inter-satellite stacking, spacer A23, fixture/carrier/seat A16-A20b, pegs/hour-ring/crank/sleeves). Engine STLs already current in repo (byte-identical to regenerated: drive 13744 tris, camring 93712 tris — no re-commit). THREE PLATES staged, Stage-1 first per brief, all black PLA Matte, anti-string overrides (retract 1.6, 210C, prime tower):
  · plate-19-calendar-core: 42 sun + 33 month + 34 feb + 35 leap + 40 carrier + 43 spacer (print 3-4 for spares)
  · plate-20-drive-train: 30 drive + 32 camring + 31 sliders + 37 peg pins
  · plate-21-accessories: 38 crank + 36 hour ring + 44 post sleeves
  · Positions reuse proven layouts (plate-02/03/04); Claude Code should verify layout on compose and nudge if the audit flags overlap/off-bed (it has the slicer view). Compose in order 19 -> 20 -> 21; Ron authorized the campaign, confirm per plate at start (standing rule 1).
- 2026-07-28 20:59 · plate-19-calendar-core.gcode.3mf · plate-19 · calendar core Stage-1 (leap deferred, feb dot dropped) · started (outcome pending)
- 2026-07-28 21:05 · plate-19-calendar-core · FAILED at layer 0 — AMS did not feed tray 2 (tray_now stuck 255, wanted 2); no plastic laid, plate clean, zero waste. Likely slot-2 black PLA Matte ran out (~19th black plate; remain untracked -1%). Note: slot 3 now also loaded black PLA (fresh spool?). Recovery: confirm good slot + restart (plate still staged).
- 2026-07-28 21:33 · plate-19-calendar-core.gcode.3mf · plate-19 · calendar core Stage-1 (slot 3, leap deferred) · started (outcome pending)
- 2026-07-28 21:37 · plate-19 RESTARTED on slot 3 (slot-2 black PLA Matte was empty) — tray 3 fed OK, RUNNING. Slot-2 spool needs replacing.
- 2026-07-28 21:37 · CAMPAIGN GATE CATCHES (engine campaign, design office GREEN gate missed all three — watertight/acceptance can not see floating sub-features or overhangs): (a) 34_receiver_feb carries the unrooted witness dot (finding #70 recurrence; 33 got r2, 34 did not) — dropped for print, mark station k=0 by hand, office owes 34 r2. (b) 35_leap_shuttle E1 strike tooth is 62% cantilevered off its post — real overhang (findings #44/#89 class), DEFERRED from plate-19, office owes a print-pose fix. (c) 32_camring is the v16f detent-skirt version that can not print bare (spaghettied twice, plate-06b) — needs a raft; blocks plate-20 drive train pending raft/split decision. Also: 44_post_sleeves in repo is 68.8mm wide, not the ~129mm the handoff cited. plate-21 accessories composed CLEAN + staged. Blind layout coords in all 3 specs corrected to the printable window (x<=200,y<=192).
- 2026-07-29 07:55 · plate-19-calendar-core · finished OK (slot 3, 50 layers; paused overnight at layer 17, resumed clean). Stage-1 calendar core: ring carrier + sun (10mm column) + month r2 + feb (dot dropped) + 4 spacer spares. Bench: seat sun+satellites+carrier on board 02f, confirm the stack meshes and turns before drive train. Watch for a faint pause seam at z~3.4mm (cosmetic).

- 2026-07-28 · DESIGN OFFICE · Finding #107 (Ron caught on the printed engine; MAJOR): the sun wouldn't drive the receiver and the strike fingers couldn't rotate past the sun. Root cause = finding #79's full-column sun. Ron pointed to the original 03_sun_tower (a stepped MULTI-LEVEL sun) — confirmed in git history + measured (full gear bands r9.55 at the mesh altitudes, slim core r5.0 at the strike altitudes so fingers pass close to center). The full column both removed that relief AND grew the tip to r11.25 (bottomed 0.90mm in the mesh root = the jam). AUTHORITATIVE HEIGHTS pulled from the simulator b50 SECTION view: board 5-9; sun 9.5-19.5 (full 9.5-11/13-14.5/16.5-18, slim 11-13/14.5-16.5/18-19.5); month sat 9.5-12.5, feb 13-16, leap 16.5-19.5; drive arms 24h@5-9/23h@9.5-12.5/22h@13-16/21h@16.5-19.5. REBUILT: multi-level sun (part_42_sun_multilevel, 10mm, square key unchanged — existing post height fine); compact receiver (receiver_compact, mesh+strike ADJACENT, 3mm not 8mm, strike teeth root on the mesh disc = print supported); shortened board post (part_02h_board_v16, post to z12.5 — must stop BELOW feb at z13; the compact stack wants a SHORTER post, reversing 02g). VERIFIED: all three satellites' fingers clear the sun over a full 360deg (+0.47mm each); mesh drives 1.60mm at the full band, no jam; stacked satellites z-separated (0.5mm gaps); short post clears feb; all watertight. REVERTS #79 + #105; SUBSUMES #104 (fingers print supported) + #106 (post shorter not taller). See docs/finding-107-multilevel-sun.md.
  · NOT YET DONE (engine still won't turn until these land): drive strike arms must reach the four strike-lamina bands (currently arch-A' sliders sit at one band 5.2-8); leap shuttle (35) to compact height; re-gate + re-plate the paused engine campaign. NOT FOR PRINT yet.

- 2026-07-28 · DESIGN OFFICE · plate-19b-core-validation STAGED (finding #107 core proof). Reprint the reconciled calendar core — multi-level sun 42 + compact month receiver 33 + short-post board 02h — to physically confirm the fix BEFORE building further. BENCH TEST: (1) the sun drives the receiver with no bind (mesh 1.60mm engagement, tip 9.55 clears the root); (2) the receiver spins past the sun through a full 360deg with the strike fingers passing the slim cores (+0.47mm). All 3 watertight. PRINT NOTE: the sun's full bands overhang its slim cores (4.55mm ledges at local z3.5/z7) so it needs tree supports (spec has support on for the plate — only the sun overhangs; board/receiver are flat). Rest of the engine (drive-strike reconciliation, feb/leap, date window+numbers) is HELD until this core is proven in hand. Awaiting Ron's "yes" to print (standing rule 1).
- 2026-07-29 12:17 · plate-19b-core-validation.gcode.3mf · plate-19b · #107 core validation · started (outcome pending)
- 2026-07-29 13:08 · plate-19b-core-validation · finished OK (slot 4 full matte black, 50 layers): board 02h + multi-level sun (on tree supports) + compact receiver 33 r2. Finding #107 validation. Bench: remove sun supports (finger-clearance slim-core faces should be clean), then seat sun on square post + receiver on board post — confirm (1) sun drives receiver no bind, (2) receiver spins freely past sun over 360.

- 2026-07-28 · DESIGN OFFICE · Finding #108 (Ron bench feedback on the #107 core print): TWO binds. (1) the sun's three sections were too close vertically -> the strike fingers rubbed the full bands as they passed (the sim's compressed 10mm stack is too tight for FDM). (2) the sun<->receiver mesh over-engaged and jammed intermittently; Ron relieved it via the post bore slop. FIX: sun slim cores TALLER (3.0mm, full bands 4.5mm apart -> feb band lifted off the finger top) + slim radius 5.0->4.7, so finger clearance over 360deg goes +0.47 -> +0.77mm (vertical AND radial room). Sun teeth thinned (tooth_frac 0.40->0.32) for ~0.31mm mesh backlash; mesh still drives 1.60mm deep. Sun grows 10 -> 13.5mm (board + receiver + post UNCHANGED — only the sun retuned). PRINT: plate-19b re-tune adds xy_contour_compensation -0.06 to counter FDM oversizing (the real culprit behind the tight mesh). All watertight. Reprint the core (sun only strictly changed, but reprint all 3 to test the assembly). Awaiting Ron's yes.

- 2026-07-28 · DESIGN OFFICE · Finding #109 (Ron): print the sun as THREE separate stacked pieces to avoid supports (the one-piece sun's full-band overhangs made spaghetti). part_42_sun_piece: one identical piece = full 7t band (z0-1.5) + slim core (z1.5-4.5), square bore. Printed FULL-BAND-DOWN the diameter only shrinks going up (9.55->4.7) => NO overhang => zero supports (verified: profile non-increasing). Print x3, stack keyed on the square post, glue the column -> reproduces the #108 sun exactly (13.5mm). plate-19d-sun-pieces: 3 copies, supports OFF, xy_contour_compensation -0.06 for backlash. Supersedes plate-19c (the supported one-piece sun). Reuse board 02h + receiver 33. Awaiting Ron's yes.
- 2026-07-29 14:15 · plate-19d-sun-pieces.gcode.3mf · plate-19d · sun 3-piece #109 quiet · started (outcome pending)
- 2026-07-29 14:18 · plate-19d-sun-pieces.gcode.3mf · plate-19d · sun 3-piece #109 quiet (half-full spool) · started (outcome pending)
- 2026-07-29 14:34 · plate-19d-sun-pieces · finished OK (half-full spool slot 3/cmd-2, 22 layers, quiet slice): 3x 42_sun_piece support-free, xy_contour_comp -0.06 backlash. Started once on slot 4 then stopped at layer 0 + restarted on half-full per Ron (zero waste). Bench: stack 3 pieces keyed on square post + glue column -> multi-level sun; test in board 02h + receiver 33 (finding #107: drive + free spin). #109 support-free split validated at printer.

- 2026-07-29 21:01 UTC · REQUESTED (design office) · plate-22-post-coupon · 113_post_tolerance_coupon_v16 · finding #113 — PRINT SILENT. Satellite-post tolerance ladder: 4 stub posts r2.50/2.55/2.60/2.65 (bore r2.70), board-02h seat shoulder + 3mm bearing on each; labels = radius hundredths. Spec carries quiet overrides (default_accel 2500 / outer 2000 / travel 3000 / initial-layer 300) + xy_contour_compensation -0.06 to MATCH the board so the winning fit transfers. Single small part, no supports, ~few min. Steps: ./pc compose plate-22-post-coupon -> confirm quiet overrides + -0.06 survive reslice -> start -> watch. Purpose: Ron drops his EXISTING receiver on each post, picks snug-but-free; that radius locks into part_02h_board_v16 POST_R and the board reprints once (with fixture r59 + solid-finger receiver). Do NOT reprint the board until Ron reports the winning post.
- 2026-07-29 16:08 · plate-22-post-coupon.gcode.3mf · plate-22 · post-tolerance coupon #113 silent · started (outcome pending)
- 2026-07-29 16:33 · plate-22-post-coupon · finished OK (half-full spool, 32 layers, quiet, no supports): finding #113 satellite-post tolerance ladder r2.50/2.55/2.60/2.65 (bore r2.70), xy_comp -0.06 matched to board so winning fit transfers. Bench: drop existing receiver on each post, pick snug-but-free; that radius -> part_02h_board POST_R. Board reprint HELD until Ron reports the winning post.
- 2026-07-29 16:36 · BENCH · finding #113 RESULT (Ron): winning post = r2.65 (nicest — snug-but-free; tightest rung, 0.05mm radial clearance to bore r2.70). POST_R LOCKS to 2.65. Next: design office regenerates part_02h_board_v16 with POST_R=2.65 (carry xy_contour_compensation -0.06) + fixture r59 + solid-finger receiver -> board reprints ONCE. Holding board reprint until that drop lands.

- 2026-07-29 21:44 UTC · REQUESTED (design office) · plate-23-board-refit · 02h_board (POST_R 2.65) + 49_fixture_r59 + 33_receiver_month_compact · findings #113/#111/#110 — PRINT SILENT. The one clean core reprint after the coupon. Board post LOCKED to r2.65 (won plate-22 ladder: snug/no-wobble/still-spins). Fixture r59 drops the sun 1mm (z9.5->8.5). Receiver has SOLID finger bars (no disconnected tips). Reuse the already-printed 3-piece sun. MANDATORY xy_contour_compensation -0.06 (the value r2.65 was chosen under; changing it shifts the fit). Quiet overrides in spec. WATCH: receiver finger tips are a ~2.5mm cantilever (r15.8->18.3, z1.5) — solid bar should bridge fine; if tips droop, add build-plate-only tree support next round. Steps: ./pc compose plate-23-board-refit -> confirm quiet + -0.06 survive reslice -> start -> watch. Then Ron re-benches the full core: post fit, sun flush, finger pass, rotation/reverse through New Year.
- 2026-07-29 16:53 · plate-23-board-refit.gcode.3mf · plate-23 · board refit POST_R 2.65 #113 silent · started (outcome pending)
- 2026-07-29 19:01 · plate-23-board-refit · finished OK (half-full spool, 120 layers, quiet silent): POST_R 2.65 board + fixture r59 + solid-finger receiver 33, xy_comp -0.06. Receiver fingers got Bridge toolpaths (no supports) — print ran clean past the z1.5 bridge zone. Bench: (1) POST_R-2.65 seat test — receiver drops on board post snug-but-free; (2) INSPECT receiver finger tips for droop (stop-and-tell -> build-plate-only tree support next round if drooped); (3) full core mesh: sun (3-piece stack) drives receiver, spins free (#107/#108/#113 all on this stack).

- 2026-07-30 01:15 UTC · REQUESTED (design office) · plate-24-slop-and-mesh · #114 sleeve ladder + #115 involute mesh coupon · PRINT SILENT, ONE PLATE. Two hand-tests together. #114: 3 drop-in star-hub sleeves, tube bore 4.27/4.22/4.17 on the r4.15 board post (labels = bore hundredths) -> swap each into the board, pick snug-but-free, kills the board-post play that still binds after #113. #115: mesh coupon (base + 2 posts @ CD 23.75, 7t profile-shifted involute sun + 12t involute sat w/ grip pin) -> feel the new flank form (sim proved 0.00mm2 tooth overlap vs 0.42 for the trapezoid) before we regenerate the full sun tower + receiver laminae. 6 parts, all flat, NO supports. xy_contour_compensation -0.06 (matches r2.65 posts + build). Layout verified collision-free, extent x[32,221] y[54,169]. Steps: ./pc compose plate-24-slop-and-mesh -> confirm quiet overrides + -0.06 survive reslice + all 6 parts present -> start -> watch.

- 2026-07-30 01:40 UTC · UPDATED (design office) · plate-24-slop-and-mesh · #115 mesh coupon parts MATCHED to engine heights. Replaced the flat 5mm sun/sat stand-ins with the REAL parts in involute form: sun = multi-level month section (full band z0-1.5 + slim core z1.5-4.5), receiver = compact involute (mesh lamina + solid fingers). Both seat at z3.5 -> mesh lamina meets sun full band coplanar (3.5-5.0), fingers clear slim core 0.75mm. New STLs 115_meshtest_sun_piece_inv + 115_meshtest_receiver_inv (old sun7t/sat12t stand-ins now unreferenced). Sleeve ladder #114 unchanged. If plate-24 hasn't sliced yet, this is the version to print. Layout re-verified collision-free x[27,223] y[49,164].
- 2026-07-29 20:34 · plate-24-slop-and-mesh.gcode.3mf · plate-24 · slop + involute mesh coupon silent · started (outcome pending)
- 2026-07-29 21:26 · plate-24-slop-and-mesh · finished OK (half-full spool, 40 layers, quiet): 3 central sleeve hubs (ID 27/22/17) + involute mesh coupon (base + sun_piece_inv + receiver_inv). xy_comp -0.06, supports off. Top row reflowed left (receiver_inv was off-bed at x223). Bench: (1) slop ladder — try each sleeve ID on the post, pick best radial fit; (2) involute mesh coupon — sun_piece drives receiver, judge backlash under -0.06. Note to design office: layout collision-verifier passed a layout that ran off-bed (x223 > printable) — add bed-bounds check.

- 2026-07-30 02:10 UTC · RESULT (Ron) · plate-24 · sleeve id17 (bore 4.17) WINS the central-bearing fit -> lock 4.17 into the real star hub. BUT the #115 involute sun/sat coupon still BINDS.
- 2026-07-30 02:12 UTC · REQUESTED (design office) · plate-25-mesh-backlash-ladder · #116 · PRINT SILENT. Diagnosed the coupon bind: the profile shift blew the sun tooth to 4.28mm at pitch (fatter than nominal 3.93) -> no room for FDM swell -> jam. Fix: DROP the shift (clean stub involute x=0; this mesh only ORIENTS, no torque, so tooth strength is moot) + open backlash. Ladder: 3 mesh pairs (7t sun + 12t receiver), clean involute, backlash 0.5/0.9/1.3, gear bores opened to 2.80 so post friction can't fake a bind. Labels: receiver 05/09/13, sun last-digit; base labels each post pair. 7 parts flat, no supports, xy-comp -0.06. Steps: ./pc compose plate-25-mesh-backlash-ladder -> confirm quiet + -0.06 + all 7 parts -> start -> watch. Ron spins each pair, first that rolls free -> lock that backlash into the real sun tower + receiver laminae.

- 2026-07-30 13:05 UTC · REQUESTED (design office) · plate-26-finger-fix · #117 · PRINT SILENT. Ron's bench: the receiver finger overhang DROOPS in print and lands on the sun full-band tooth top (zero designed clearance); forcing under cams the receiver up over the sun. Fix, both sides: sun full band shortened z0-1.0 (top now 0.5mm below finger bottom) + finger split (full-height only where disc-backed r<16; overhang tip raised, underside 1.2mm above the band so droop lands in air). Sun also carries #116 thin clean involute (no shift). 2 parts only, REUSE the plate-24 base/posts. Flat, no supports, xy-comp -0.06. Steps: ./pc compose plate-26-finger-fix -> confirm quiet + -0.06 -> start -> watch.
- 2026-07-30 09:24 · plate-25-mesh-backlash-ladder.gcode.3mf · plate-25 · mesh backlash ladder #116 silent · started (outcome pending)
- 2026-07-30 10:51 · plate-25-mesh-backlash-ladder · finished OK (half-full spool, 45 layers, quiet): base + 3 sun/receiver pairs at backlash 0.5/0.9/1.3 (rec 05/09/13). xy_comp -0.06, supports off. Layout reflowed (recs+bl13 pair were off-bed). Bench: mesh each pair, pick the backlash that drives clean without wedging (#116). plate-26 finger-fix staged, waiting on bed-clear.
- 2026-07-30 11:40 · plate-26-finger-fix.gcode.3mf · plate-26 · finger-fix #117 silent · started (outcome pending)
- 2026-07-30 11:59 · plate-26-finger-fix · finished OK (half-full spool, 37 layers, quiet): revised 115_meshtest_sun_piece_inv (band -0.5mm below finger) + receiver_inv (finger tip +1.2mm clear). allow_midair on receiver (raised fingers overhang into air, bridge/overhang toolpaths, no supports). Reuse plate-24 base. Bench: mesh sun vs receiver on the plate-24 base — confirm finger CLEARS the sun tooth now instead of hitting it (#117). Finger tips may show harmless droop.

- 2026-07-31 · REQUESTED (design office) · plate-27-ballmesh · #121 FINAL patent-form pair · PRINT SILENT. Sun: 7 mushroom BALL teeth r2.0 (tips 9.55) — Ron's read of Fig.2: the ball tips are the anti-bind mechanism for the climbing epicyclic mesh. Month gear: the balls' own swept conjugate (sockets match the ball curve, clr 0.15, full 84-engagement hunting cycle) with crests sculpted into tall rounded teeth like drawn wheel 210. Sim: 0.00mm2 overlap, free play 1.28deg (0.33mm), wedge-proof fwd+rev. 2 parts, bores 2.80 (drop on the coupon base posts, CD 23.75), flat, NO supports. Steps: ./pc compose plate-27-ballmesh -> gate watertight/grounded -> confirm quiet overrides + xy_contour_compensation -0.06 survive reslice -> start -> watch.
- 2026-07-30 22:08 · plate-27-ballmesh.gcode.3mf · plate-27 · patent-form ball mesh #121 silent · started (outcome pending)
- 2026-07-30 22:28 · plate-27-ballmesh · finished OK (half-full spool, 45 layers, quiet): patent-form ball sun + sculpted conjugate month gear (#121). xy_comp -0.06, supports off, both flat on z0. Drop on coupon base at CD 23.75; spin month around sun by its pin — fwd/rev + shove sideways. Sim: 0.33mm play, cannot wedge. If it feels right -> this tooth form goes into the real multi-level sun tower + all 3 receivers; bind saga over. Full bench set now: involute ladder + #117 finger-fix + this ball mesh.

- 2026-07-31 · REQUESTED (design office) · plate-28-ballsun-keyed · #121 keyed ball sun for the REAL rig · PRINT SILENT. Same patent-form ball sun (7 mushroom teeth r2.0) with the SQUARE keyed bore hw2.25 -> seats stationary on fixture r59's square post (key starts z8.5). 4.0mm tall: teeth span assembly 8.5-12.5, covering the ballmesh month gear on the board 02h post (band 9.5-12.5). 1 part, flat, NO supports. Steps: ./pc compose plate-28-ballsun-keyed -> gate -> confirm quiet overrides + xy_contour_compensation -0.06 survive reslice -> start -> watch. Bench after: keyed ball sun on fixture post + ballmesh month gear on board post -> crank the board fwd/rev, the month gear climbs the patent sun on real hardware.
- 2026-07-31 10:46 · plate-28-ballsun-keyed.gcode.3mf · plate-28 · keyed ball sun #121 silent · started (outcome pending)
- 2026-07-31 10:57 · plate-28-ballsun-keyed · finished OK (half-full spool, 20 layers, quiet): #121 ball sun with square keyed bore (hw 2.25), 4mm. xy_comp -0.06, supports off. Bench: seat on the keyed post (board+fixture rig), drive the month gear mounted on-axis — confirm the free-spin no-wedge action holds when constrained. If good -> geometry into the multi-level sun tower + all 3 receivers.

- 2026-07-31 · REQUESTED (design office) · plate-29-month-b270 · #122 satellite-shaft slop fix · PRINT SILENT. Ron's bench: visible slop between the ballmesh month gear and the board post — root cause: that gear shipped with bore 2.80 (deliberately loose for the ladder base), but the proven board-post fit is #113's winner: r2.65 post / 2.70 bore = 0.05mm radial. Same patent-form month gear re-emitted at bore 2.70. 1 part, flat, NO supports, xy-comp -0.06 (the fit was chosen under it). Steps: ./pc compose plate-29-month-b270 -> gate -> confirm quiet + -0.06 -> start -> watch.
- 2026-07-31 11:25 · plate-29-month-b270.gcode.3mf · plate-29 · month bore 2.70 #122 silent · started (outcome pending)
- 2026-07-31 11:41 · plate-29-month-b270 · finished OK (half-full spool, 45 layers, quiet): ball-mesh month gear bore 2.80->2.70 (#122, #113-winning 0.05mm fit on r2.65 post). xy_comp -0.06, supports off. Bench: seat month on the board post beside keyed ball sun (plate-28), drive the full rigged mesh — patent tooth form + locked post fit on the real axis.

- 2026-07-31 · REQUESTED (design office) · plate-30-ballmesh-grown · #123 print-shrink compensation · PRINT SILENT. Ron's calipers: both ballmesh gears printed Ø0.5 SMALL (ball apexes + comp + shrink) -> engagement collapsed 1.6->~1.0mm -> satellite spun 360 without engaging the sun. Fix: both gears re-emitted DILATED +0.25mm radius, conjugate re-swept on the grown geometry (design sun tip 9.79 / month 16.05 -> printed ~9.55/15.80 = intended envelope + 1.6mm engagement). Same square-key sun + b270 month. Keep xy-comp -0.06 (loss measured under it — identical process). Steps: ./pc compose plate-30-ballmesh-grown -> gate -> confirm quiet + -0.06 -> start -> watch. Bench: calipers on both (expect sun Ø~19.1, month Ø~31.6), then the climb test on board+fixture.

- 2026-07-31 · REQUESTED (design office) · plate-31-ballmesh-tight · #124 seat-tightened pair · PRINT SILENT. Ron's patent read: the ball must touch BOTH satellite flanks when seated (his measured ball 3.6 in a 5.2 opening = shrunken plate-27 parts). Fix layers: (a) #123 grow restores printed ball to ~4.0; (b) THIS pair halves the socket SEAT clearance 0.15->0.08/side (seated gap ~0.16 design) with walls raised — conjugate re-swept, design overlap 0.00. The socket MOUTH stays wide by kinematic necessity (sub-pitch balls slide through the socket during the climb; narrowing the mouth binds). A/B against the plate-30 pair. 2 parts, flat, no supports, xy-comp -0.06. Steps: ./pc compose plate-31-ballmesh-tight -> gate -> confirm quiet + -0.06 -> start -> watch.
- 2026-07-31 16:11 · plate-30-ballmesh-grown.gcode.3mf · plate-30 · ballmesh grown +0.25r #123 silent · started (outcome pending)
- 2026-07-31 16:33 · plate-30-ballmesh-grown · finished OK (half-full spool, 45 layers, quiet): grown pair (+0.25mm radius to counter Ron's calipered Ø0.5 print-shrink) — 121g_ballsun_keyed_grown + 121g_month_b270_grown. xy_comp -0.06, supports off. Bench: calipers first (ball ~4.0, sun Ø~19.1, month Ø~31.6 = grow confirmed), mount+crank. plate-31 tight-seat A/B staged, waiting on bed-clear.

- 2026-07-31 · REQUESTED (design office) · plate-32-ballmesh-deep · #125 Ron's spec: month teeth +1mm longer, +0.5mm wider · PRINT SILENT. Teeth survive the full climb-sweep INTACT (stems + high-core blank); printed engagement ~2.6mm (was 1.6) — the sun valley finally filled. Sun re-carved as mutual conjugate (valleys relieved for the deeper teeth): USE AS A PAIR — older suns will bind with this month gear. Grown sizing (+0.25 r), seat CLR 0.08, design overlap 0.00. Square-key sun + b270 month. ENGINE CAVEAT logged: printed month tip ~16.8 -> ~0.19mm 23h drive-arm clearance, re-verify before engine adoption. Steps: ./pc compose plate-32-ballmesh-deep -> gate -> confirm quiet + -0.06 -> start -> watch.
- 2026-07-31 17:52 · plate-32-ballmesh-deep · STAGED (not started; runs after plate-31): 125_ballsun_keyed_deep (valley-relieved) + 125_month_b270_long (teeth +1/+0.5, tip ~16.8, engagement 2.6mm). Gated watertight+grounded, xy_comp -0.06, quiet, supports off. FLAG for the record (#125): at printed tip ~16.8 the month passes the FUTURE 23h drive arm with only ~0.19mm — fine for all bench tests, but before this length enters the full engine, re-verify that sweep or shave the arm dip. Queue: plate-31 (tight A/B) FIRST on bed-clear, then plate-32.
- 2026-07-31 17:59 · plate-31-ballmesh-tight.gcode.3mf · plate-31 · ballmesh tight seat #124 silent · started (outcome pending)
- 2026-07-31 18:20 · plate-31-ballmesh-tight · finished OK (half-full spool, 45 layers, quiet): grown geometry, socket seat clearance halved 0.08/side (#124) — 124_ballsun_keyed_tight + 124_month_b270_tight. xy_comp -0.06, supports off. Bench A/B vs plate-30 (baseline) + plate-32 (deep). plate-32 next on bed-clear.

- 2026-07-31 · REQUESTED (design office) · plate-33-ballmesh-square · #126 square-tip max-depth month teeth · PRINT SILENT. Ron: +2mm tip and SQUARE ends. +2 was geometrically impossible (teeth would strike the sun hub); achieved +1.15 over plate-32 by shrinking the sun core 6.3->5.3: square blank tip 18.2 -> climb-sweep carved 17.91, corners auto-relieved just enough to roll. Teeth dive PAST the ball centers (r5.84); printed engagement ~3.5mm. Zero design overlap. MATCHED PAIR ONLY (sun valleys re-carved; do not mix with older parts). ENGINE CAVEAT: this tooth length exceeds the 23h drive-arm dip — bench-only until the arm is re-planned. Steps: ./pc compose plate-33-ballmesh-square -> gate -> confirm quiet + -0.06 -> start -> watch.

- 2026-07-31 · REQUESTED (design office) · plate-34-ballmesh-flat25 · #127 · PRINT SILENT. Ron's refinement of #126: month tooth tips now a TRUE 2.5mm FLAT square face (flanks 3.5, chamfered corners, tip radius set just under the climb-sweep carve limit so the flat survives untrimmed). Slim-core sun + max depth kept; printed engagement ~3.4mm; zero design overlap. MATCHED PAIR ONLY. ENGINE CAVEAT unchanged (bench-only length). Steps: ./pc compose plate-34-ballmesh-flat25 -> gate -> confirm quiet + -0.06 -> start -> watch.

- 2026-08-01 · REQUESTED (design office) · plate-35-ballmesh-flattrue · #128 TRUE flat square tips · PRINT SILENT — and SKIP plate-34 (superseded; its 'flat' had been shaved to a point by the climb-sweep). Ron annotated the render: blunt rectangular tips. Fix: truncate at r16.25 where the tooth is genuinely 2.5mm wide -> 2.6mm flat face, square corners, removal-only (zero overlap inherited). Engagement ~1.85mm printed. This plate prints BOTH parts (127 sun + 128 month) — matched pair. ENGINE CAVEAT unchanged. Steps: ./pc compose plate-35-ballmesh-flattrue -> gate -> confirm quiet + -0.06 -> start -> watch.
- 2026-07-31 19:16 · plate-35-ballmesh-flattrue.gcode.3mf · plate-35 · true-flat square tips #128 silent · started (outcome pending)
- 2026-07-31 19:20 · plate-35-ballmesh-flattrue.gcode.3mf · plate-35 · true-flat tips #128 (standard speed, Ron) · started (outcome pending)
- 2026-07-31 19:37 · plate-35-ballmesh-flattrue · finished OK (half-full spool, 45 layers, STANDARD SPEED per Ron — quiet accel/speed dropped, geometry + xy_comp -0.06 unchanged): 127_ballsun_slimcore + 128_month_flattrue (TRUE flat square tips, 2.6mm face at r16.25, engagement ~1.85mm; supersedes plate-34 whose flats got shaved to points). Tips printed AS-DESIGNED, no shortening. Bench: crank flat pair vs pointy deep pair (plate-32) on the same sun — whichever feels like Oechslin drew it, the engine inherits. Committed silent spec restored in repo.

- 2026-08-01 · REQUESTED (design office) · plate-36-ballmesh-prong · #130 stepped square tooth · PRINT SILENT. Ron's refinement: the +1.0mm extension is a STRAIGHT-SIDED 1.2mm rectangle (flat end r17.27) standing on the #128 2.6mm flat shoulder. Prong verified inside the climb corridor; direct roll scan 0.00mm2; engagement ~2.8mm printed. Pairs with 127_ballsun_slimcore (reuse plate-35's print or this plate reprints it). ENGINE CAVEAT unchanged (bench-only length). Steps: ./pc compose plate-36-ballmesh-prong -> gate -> confirm quiet + -0.06 -> start -> watch.

- 2026-08-01 · REQUESTED (design office) · plate-37-ballmesh-widesquare · #131 full-width square teeth · PRINT SILENT. Ron's annotated bracket realized: month teeth are 2.3mm straight-sided rectangles root-to-tip, flat end r17.19, FILLING the sun valleys. Enabled by co-design: sun balls r2.0->r1.6 (centers 8.20, nearer pitch -> less slide -> deep corridor 2.46mm). Engagement ~2.74mm printed, roll overlap 0.00. NEW MATCHED PAIR (both on this plate; never mix with earlier suns/months). ENGINE CAVEAT unchanged. Steps: ./pc compose plate-37-ballmesh-widesquare -> gate -> confirm quiet + -0.06 -> start -> watch.
- 2026-07-31 20:14 · plate-37-ballmesh-widesquare.gcode.3mf · plate-37 · wide-square month + r1.6 ball sun #131 silent · started (outcome pending)
- 2026-07-31 20:36 · plate-37-ballmesh-widesquare · finished OK (half-full spool, 45 layers, quiet slice): 131_ballsun_r16 (square-keyed sun, r1.6 balls) + 131_month_widesquare (full-width 2.3mm square teeth, bore 2.70). Co-designed matched corridor — pair ONLY with each other. xy_comp -0.06, supports off. Skipped plate-36 (superseded). Bench: sun on fixture post + month on board post, crank — square teeth drop into widened valleys, climb clean fwd/rev. The screenshot shape, printed. If it wins -> full sun tower + receivers.

- 2026-08-01 · REQUESTED (design office) · plate-38-patent-pair · #133 THE PATENT PAIR · PRINT SILENT. Both tooth forms traced from Fig.2 (sun = 203's smooth-wave star x7; month = 210's wave teeth x12, tip 16.40 -> 57% into the sun valley per Ron's read) — and they are mutually conjugate AS DRAWN: zero shave, 0.00mm2 overlap through the full climb. Tight fit doctrine: mesh CLR 0.08; bearings at proven tightest-that-still-moves; NEW anti-tilt hub boss on the month gear (bearing 3->6mm). Engagement ~2.2mm printed. MATCHED PAIR. ENGINE CAVEAT: month tip 16.40 -> ~0.6mm 23h-arm clearance, re-verify at adoption. Steps: ./pc compose plate-38-patent-pair -> gate -> confirm quiet + -0.06 -> start -> watch.

- 2026-08-01 · UPDATED (design office) · plate-38-patent-pair · #133b CLOCKED SUN (supersedes the 133 sun; if plate-38 already sliced with 133, re-compose). Ron's spec (finding #134, sun side): the sun's VALLEY must face the strike line — world 0deg, aligned square to the keyed-post faces — so the satellite tooth sits SANDWICHED between two sun teeth when the 24h wheel strikes. The 133 sun was half a pitch off (tooth peak at 0deg). 133b rotates the profile 25.7deg vs the square bore; verified valley at 0deg (r5.59 vs tooth 9.6). Month gear (133) unchanged. Print silent as before.

- 2026-08-01 · UPDATED (design office) · plate-38-patent-pair · #133c SYMMETRIC pair (supersedes 133/133b; Ron caught asymmetric teeth in the render — a reversibility-law violation from tracing skew). Both traced teeth mirror-averaged about their true axes: flank asymmetry 0.40/0.24 -> 0.0000 on both wheels. Pair re-carved as mutual conjugates (overlap 0.00), sun re-clocked valley-to-strike-line per #134. Spec now points at 133c_sun_sym_clocked + 133c_month_sym. If previously composed, RE-COMPOSE. Print silent as before.

- 2026-08-01 · UPDATED (design office) · plate-38-patent-pair · #133d FINAL (supersedes 133/b/c) · PRINT SILENT. Ron's mesh-zone zoom: 214 heads are FAT and FLAT-crested on narrower necks, form-fitting the sun valley. Rebuilt: flat crest 3.3 wide on 2.2 neck (reentrant, as drawn), conjugate-carved against the sun = the valley's perfect match (CLR 0.08); sun mutually re-carved + VALLEY-to-strike clocking kept. SEATED-PHASE PLAY 0.00deg — the #134 strike sandwich locks solid. Overlap 0.00, symmetric, hub boss, GROW. Spec -> 133d_sun_final + 133d_month_fathead. RE-COMPOSE if previously composed. Steps: ./pc compose plate-38-patent-pair -> gate -> quiet + -0.06 -> start -> watch.
- 2026-08-01 08:41 · plate-38-patent-pair.gcode.3mf · plate-38 · patent pair 133d fathead #133d silent · started (outcome pending)
- 2026-08-01 09:02 · plate-38-patent-pair · finished OK (half-full spool, 45 layers, quiet slice): 133d_sun_final + 133d_month_fathead (fat flat-headed 214 teeth form-fitting the sun valley, seated play 0.00, per Ron zoom on patent sheet). xy_comp -0.06, supports off. Matched pair. Bench: mount + crank — zero seated slop, climb clean fwd/rev. If it feels like Oechslin drew it -> full sun tower + all 3 receivers, bind saga closed.
- 2026-08-01 09:23 · BENCH (Ron) · FINDING: too much play in the board post, sun post, AND satellite post. Diagnosis: board post r2.65 / month bore r2.70 = 0.05mm radial clearance — the #113 coupon-picked "snug-but-free" value, but chosen on a SHORT coupon. Full 9mm-tall parts lever that same 0.05mm radial into visible tip wobble; sun+satellite posts share the coupon-derived clearance so all three feel loose. Print tolerance likely adds more (bore prints large, post small). Possible secondary: verify xy_contour_compensation -0.06 is contour-only (Bambu) and not enlarging bores. FIX (design office, parametric): tighten post-fit clearance toward ~0.02-0.03 radial and/or grow posts on all three. Recommended method: a full-height tighter post-fit coupon ladder (rungs 0.02/0.03/0.04 radial) so Ron re-picks on parts that lever like the real ones — same method that dialed r2.65. Ball-mesh tooth form itself is NOT the issue.

- 2026-08-01 · REQUESTED (design office) · plate-39-fullheight-fits · #135 full-height fit ladder · PRINT SILENT. Ron: too much play in board/sun/satellite posts. Root cause refined beyond the coupon-height point: xy_contour_compensation -0.06 shrinks OUTER contours only — bores unchanged but every POST/KEY prints ~0.06/side small → nominal 0.05 fits are ~0.11 real; sun square key ~0.3 rattle in the 4.50 bore. Fix = bake +comp into post/key sizes, re-picked at FULL height on this ladder: Station A round posts 8mm, design r 2.70/2.73/2.76 (labels 70/73/76) — test with 133d month gear. Station B square keys 12mm, design across 4.42/4.50/4.58 (K4/K5/K6) — test with 133d sun. Winners get baked into board 02h, fixture r59, and every post in the engine regen. Steps: ./pc compose plate-39-fullheight-fits -> gate -> quiet + -0.06 -> start -> watch. (Print alongside/after plate-38's 133d pair — the pair are the gauges for this ladder.)
- 2026-08-01 09:37 · plate-39-fullheight-fits.gcode.3mf · #135 · started (outcome pending)
- 2026-08-01 09:38 · plate-39-fullheight-fits (#135 full-height fit ladder) STARTED on slot 2 (black PLA Matte). Bed confirmed clear by Ron. Speed mode set to STANDARD (spd_lvl=2) per Ron — quiet SLICING profile still baked in (outer_wall 60, accels reduced) so runtime speed differs from silent but dimensions unaffected. Gate-confirmed in sliced gcode: xy_contour_compensation=-0.06 (posts print small, as production) + xy_hole_compensation=0 (bores hold nominal — confirms contour-only root cause). Station A round posts r2.70/2.73/2.76 (gauge: 133d month bore 2.70). Station B square keys 4.42/4.50/4.58 (gauge: 133d sun bore 4.50). Ron picks snug-but-moves per station.
- 2026-08-01 10:31 · plate-39-fullheight-fits (#135 full-height fit ladder) FINISHED CLEAN — 75/75 layers, Standard speed, slot 2 black PLA Matte. Snapshot: all 6 uprights standing (3 round posts Station A 70/73/76 @ r2.70/2.73/2.76; 3 square keys Station B K4/K5/K6 @ 4.42/4.50/4.58), no spaghetti/topple. -0.06 comp + xy_hole_comp 0 verified in gcode. NEXT (Ron, bench): gauge Station A posts with 133d month (bore 2.70) -> pick snug-but-moves (70/73/76); Station B keys with 133d sun (bore 4.50) -> pick (K4/K5/K6). Winners become baked-in +comp post/key sizes across board 02h, fixture r59, all posts.

- 2026-08-01 · REQUESTED (design office) · plate-40-fits-locked · #136 Ron's #135 ladder picks baked in · PRINT SILENT. '70' -> board 02h satellite post DESIGN r2.70 (prints ~2.64 vs the 2.70 bore — the comp shrink IS the running clearance; old 2.65 double-counted it). 'K4' -> fixture r60 square key DESIGN 4.42 across (prints ~4.30 vs the sun's 4.50 bore; old 4.30 rattled 0.3). LAW (all future parts): design posts/keys AT the mate bore size under xy-comp -0.06. Board + fixture on one plate; pair with the 133d gears from plate-38. Steps: ./pc compose plate-40-fits-locked -> gate -> quiet + -0.06 -> start -> watch.

- 2026-08-01 · REQUESTED (design office) · plate-41-board-tight · #137 tighter BOARD wheel · PRINT SILENT. Ron: board wheel too loose. Audit of the board's fit chain found THREE compounding faults: (1) the #114 'id17' winner (bore 4.17) was never baked into the real star hub — still 4.35, giving 0.26mm radial play on the ~4.09 printed post [hub bore -> 4.17, fixture round post designed AT bore 4.17 -> prints ~4.11 = 0.06]; (2) the hub->board PRESS fit was actually 0.06 LOOSE (OD 5.45 prints 5.39 into a 5.45 bore) and that slop shifts CENTER DISTANCE into the mesh [OD -> 5.53 = 0.02 real interference]; (3) bearing only 3.7mm vs a 42mm rim (11:1 lever) [tube -> 5.0mm, max clearing the key start z8.5]. Net rim wobble 2.95 -> 0.50mm. Fixture r61 keeps Ron's K4 key. Board 02h UNCHANGED — the plate-40 print stays good. NOTE: the hub is now a genuine press fit; expect to tap it into the board bore. Steps: ./pc compose plate-41-board-tight -> gate -> quiet + -0.06 -> start -> watch.
- 2026-08-01 11:47 · plate-41-board-tight.gcode.3mf · #137 · started (outcome pending)
- 2026-08-01 11:47 · plate-41-board-tight (#137 tighter board wheel) STARTED slot 2, Standard speed (spd_lvl 2), quiet slicing + xy_contour_compensation=-0.06 (hole_comp 0) verified in gcode. Parts: 50e_star_hub + 49_fixture_r61 (keeps Ron K4 key 4.42). REFLOW: design office placed star hub blind at [90,180] -> ran 16.5mm off back edge (Y to 208.5 vs 192 limit); I moved it to [90,156] (Y[127.5,184.5]), clears fixture top by 9.5mm and back edge by 7.5mm. Both objects survived slice. Fixes in #137: hub bore 4.35->4.17 (id17 winner finally baked), hub OD 5.45->5.53 for real 0.02 press into board, bearing tube 3.7->5.0mm. NOTE: hub is now a real press fit into board 02h -> expect to tap it in. Board 02h NOT reprinted (plate-40 still good).
- 2026-08-01 13:19 · plate-41-board-tight (#137) FINISHED — 120/120 layers, Standard speed, slot 2, no fault/pause during run. Snapshot at 13:19 is oblique (parts off-frame/shadow) — printer-confirmed complete but NOT visually verified; defer part-quality to Ron bench check. NEXT (Ron, bench): (1) star hub 50e -> board 02h is now a REAL press fit (0.02mm interference) — expect to TAP it in; check it seats square and the bearing tube (now 5.0mm) reduces rim wobble. (2) fixture r61 carries K4 key (4.42) + round post at bore-size (4.17->prints ~4.11) into hub bore 4.17 = 0.06 target. Report: does hub tap in snug (not loose, not cracking board)? does rim wobble feel killed vs before? Board 02h from plate-40 NOT reprinted.

- 2026-08-01 · BENCH RESULT (Ron) + REQUESTED · plate-42-ronpair-sun · #138 · PRINT SILENT. WINNER FOUND: with the #136/#137 tight posts, Ron's CROSS-pair works — 131_month_widesquare on 127_ballsun_slimcore (different generations, which the old "matched pairs only" rule forbade). Sim explains it: as-modelled that mix grazes 0.126mm2, but BOTH parts shrink 0.06/side printed and that 0.12 of built-in backlash absorbs the mismatch (residual 0.028 — a graze that wears in). LAW CORRECTED: a pair must clear AFTER shrink, not as-modelled. Engagement 3.12mm (deepest of any pair we built), seated play 0.00deg (satisfies the #134 strike-lock law), mean 3.6deg. This plate prints ONLY the sun, re-carved against Ron's exact month gear (7.3mm2 removed -> residual 0.0000) and clocked VALLEY-to-strike-line. RON KEEPS his printed 131 month gear — do not reprint. Steps: ./pc compose plate-42-ronpair-sun -> gate -> quiet + -0.06 -> start -> watch.

- 2026-08-01 · REQUESTED (design office) · plate-43-engine-v17 · #139 ENGINE SET · PRINT SILENT. Ron's winning mesh rolled into the machine. *** SUPERSEDES plate-42 — DO NOT PRINT IT: the #138 cleanup carve was a REGRESSION. It removed the residual graze but cost 1.9deg of seat tightness at the strike (0.83mm lost motion vs 0.38); per the #134 strike law the seat wins, so the sun ships UNCARVED, only CLOCKED (valley to the strike line). *** Tower = ONE piece printed x3 (band down, no supports, #109), square keyed, stacking to the month/feb/leap altitudes with slim cores at the finger bands. Three receivers carry the 131 wide-square mesh form CLOCKED per #134 — month +18.07deg, feb +6.46, leap +24.85 (sim-VERIFIED, my first derivation was half a pitch off and the sim caught it) — so a seated phase lands on each strike station; plus hub bosses (bearing 3->6mm), bore 2.70 for the #136 posts, #117 raised finger tips. GATES PASS: finger/slim-core +0.61mm, mesh engagement 3.24mm, bottoming margin 1.26mm, strike lost motion 0.38mm of a 1.12mm window (34%). OPEN GATE: confirm the 23h drive-arm z-span vs the month MESH lamina (co-planar they clash 0.20mm; not co-planar by design). 6 parts on the plate (tower piece x3 + 3 receivers). Steps: ./pc compose plate-43-engine-v17 -> gate -> quiet + -0.06 -> start -> watch.

- 2026-08-01 · REQUESTED (design office) · plate-44-carrier-v17 · #140 THREE-STATION CARRIER CHAIN · PRINT SILENT. Ron asked whether the engine plate included the tighter-post board — it did not, and the audit found a bigger gap: board 02h carries only the MONTH post, so 2 of the 3 v17 receivers had nowhere to mount. A post rising from the board to the feb station is impossible (it would spear the rotating month satellite, lamina r17.19 vs 4.81mm station spacing) — which is exactly why the patent carries stud 218 ON stud 214. Printable form: the chain is a STACK of flat pieces like the sun tower — plate + one riser each, prints flat, ZERO supports. Parts: board 02j (month post extended to assy 14.0), carrier arm 1 (12.7-14.0, presses on the month post, riser at the FEB station), carrier arm 2 (17.2-18.5, presses on the feb post, riser at LEAP), and a 1.0mm sun spacer. ALTITUDES RESOLVED: the sun tower piece is 4.5mm, so three of them put the mesh bands 4.5mm apart -> satellites now at assy 9.5/14.0/18.5 (was 9.5/13/16.5); that spacing is what makes the crossover possible (3mm satellites leave 1.5mm = 1.3 arm + 0.2 clearance). GATES PASS: arms clear the rotating fingers below by 0.20mm; all three finger bands sit inside their sun slim cores; all three mesh laminae land on their sun bands. Press fits: arm bores 2.60 on design-2.70 posts (print 2.64) = 0.04 interference, expect to tap. Prints with plate-43 to make a complete engine. Steps: ./pc compose plate-44-carrier-v17 -> gate -> quiet + -0.06 -> start -> watch.
- 2026-08-01 15:29 · plate-43-engine-v17.gcode.3mf · #141 revB · started (outcome pending)
- 2026-08-01 15:31 · plate-43-engine-v17 (#141 ENGINE SET v17 rev B) STARTED slot 2. QUIET: quiet slicing + xy_contour_compensation=-0.06 (hole_comp 0) verified in gcode; runtime Silent (spd_lvl=1) requested per Ron QUIET mode — printer held spd_lvl=2 during layer-0 prep, watch will re-apply until it latches. 6 objects (140_sun_tower_piece x3 + 141_receiver_month + 142_receiver_feb + 143_receiver_leap) survived slice; 25 layers (tallest=tower 5.0mm). REFLOW: leap receiver [195,105]->[178,105] (was 12.8mm off right edge, X to 212.8 vs 200); now X[160.2,195.8], 4.2mm inside edge, 12.4mm clear of month/feb. rev A explicitly NOT printed (would not assemble). Fixes in rev B: anti-tilt boss removed from month/feb (reverts to 3.0mm bearing), tower piece 4.5->5.0mm band pitch, finger bars start r2.0 not r4.0, all parts re-authored as watertight boolean-union slabs. Next: plate-44 carrier chain after this.
- 2026-08-01 16:25 · plate-43-engine-v17 (#141 rev B) FINISHED — 25/25 layers, QUIET (Silent spd_lvl=1 held from 28% after layer-0 prep revert; reset to 2 at completion, normal). slot 2. Snapshot oblique (6 parts off-frame) — printer-confirmed complete, no fault/pause, NOT visually verified; defer part QC to Ron bench. 6 parts on bed: 3x sun tower piece (5.0mm), receiver_month, receiver_feb, receiver_leap. Bed NOT yet cleared — plate-44 waits on Ron clearing these + fresh bed-clear confirm.
- 2026-08-01 16:28 · plate-44-carrier-v17.gcode.3mf · #141 revB · started (outcome pending)
- 2026-08-01 16:28 · plate-44-carrier-v17 (#141 CARRIER CHAIN v17 rev B) STARTED slot 2. Bed confirmed clear by Ron. QUIET: quiet slicing + xy_contour_compensation=-0.06 (hole_comp 0) verified in gcode; runtime Silent (spd_lvl=1) enforced by watch once past layer-0 prep. 4 objects (144_board_02j + 145_carrier_feb + 146_carrier_leap + 147_sun_spacer_1mm) survived slice. No reflow needed (all in bounds). rev A NOT printed. rev B fixes: satellite altitudes 9.5/14.5/19.5 on 5.0mm pitch; arm riser pad budgeted into pitch (0.20 clr + 1.30 plate + 0.50 pivot pad + 3.00 sat = 5.00); arm plate re-authored as plane polygon with real interior ring (rev A union filled the bore); 1mm sun spacer now generator-emitted. Press fits: arm bores 2.60 on design-2.70 posts (prints 2.64) = 0.04 interference, expect to tap. NEXT: Ron reports arm-bore-on-post fit + hub->board 02j press + carrier arm seating.
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

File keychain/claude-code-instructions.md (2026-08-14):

# Making a Chewy-style name keychain with Claude Code

The easiest path: put the included `make_keychain.py` in a folder, open Claude Code there, and paste the prompt below. The script already encodes everything reverse-engineered from the original Federico model, so Claude Code only needs to set up dependencies and run it.

## Prompt to paste into Claude Code

```
I have a script make_keychain.py in this folder that generates a 3D-printable
name keychain (bubble-letter style, Chewy font). Please:

1. Install its Python dependencies:
   pip install numpy shapely trimesh matplotlib manifold3d mapbox_earcut rtree fonttools brotli
2. Get the Chewy font as chewy.ttf in this folder. If Google Fonts or GitHub
   is unreachable, use npm:
     npm install @fontsource/chewy
     python3 -c "from fontTools.ttLib import TTFont; f=TTFont('node_modules/@fontsource/chewy/files/chewy-latin-400-normal.woff2'); f.flavor=None; f.save('chewy.ttf')"
3. Run: python3 make_keychain.py <NAME>
4. Confirm the output says "watertight, 1 body(ies)" and give me the
   <NAME>.stl and <NAME>.3mf files.

Make one for the name: Taashvi
```

## What the script does (the design spec, if you ever want it rebuilt from scratch)

The style is a clone of the MakerWorld "Portachiavi Nome Parametrico Personalizzabile" (Stampa 3D AV Studio), reverse-engineered from an exported 3MF:

- **Font**: Chewy (Google Fonts), rendered at 0.305 mm per unit of a size-100 TextPath (≈17 mm cap height).
- **Letter layout**: each glyph advances 0.80× its normal advance width, so adjacent letters overlap. Any pair that still overlaps by less than 2.5 mm² is nudged closer in 0.1 mm steps until it does — this is what fuses the word into one printable piece.
- **Heights**: letters alternate — 1st, 3rd, 5th… extrude to 6.5 mm; 2nd, 4th… to 4.5 mm. All start at z = 0.
- **Keyring loop**: annulus, 10.14 mm outer diameter, 5 mm hole, 4.5 mm thick, vertically centered 1.5 mm below the word's midline, slid rightward until it overlaps the first letter by ≥ 4 mm² while keeping the hole clear.
- **Dots on i/j**: lowered until they overlap their stem by ≥ 1.5 mm² so the model is a single body (the original leaves them floating as separate pieces).
- **Output**: boolean union via manifold3d, centered on a 256 mm plate, exported as STL + 3MF. Sanity checks: mesh watertight, exactly 1 body.

## Printing notes

- No supports needed; prints flat side down.
- Any color; the original used a single filament. The 2 mm height difference between alternating letters lets you do a filament swap at z = 4.5 mm for a two-tone effect.

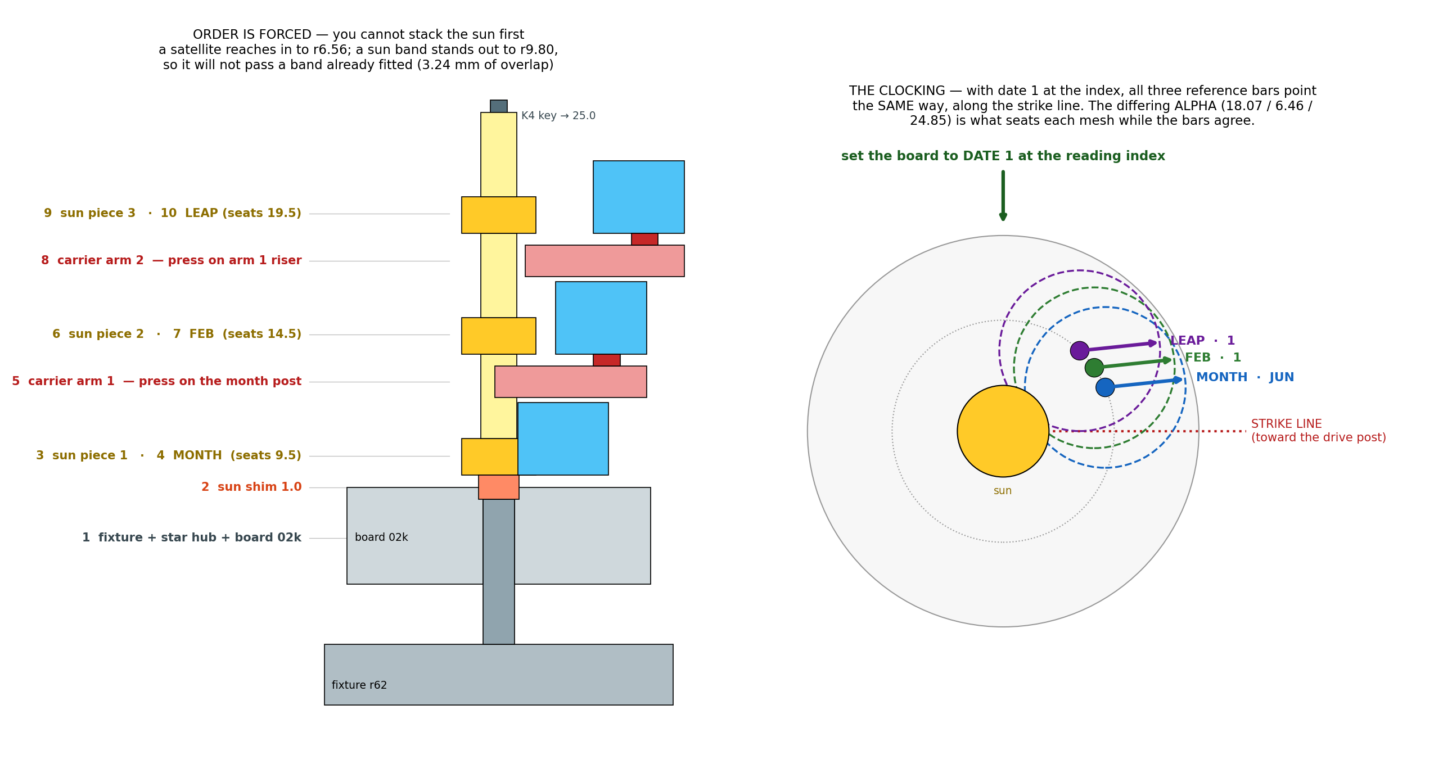
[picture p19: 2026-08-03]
docs/assembly_card.png

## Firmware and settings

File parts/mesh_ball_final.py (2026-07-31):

#!/usr/bin/env python3
"""#121 FINAL — the patent-form mesh pair, bench coupon edition.

Sun: 7 mushroom ball teeth (r2.0, tips at the 9.55 envelope) — Ron identified the
ball tips as the anti-binding mechanism for the climbing (epicyclic) mesh.
Month gear: mutual-envelope conjugate of the sun (sockets swept by the balls
themselves through the full 84-engagement hunting cycle, clearance 0.15), then
crests sculpted into tall rounded teeth (core 14.3, lobes r1.5) to match the drawn
month wheel 210 — material-removal-only, so the zero-overlap proof is inherited.
Sim: 0.00mm^2 overlap through the roll, free play 1.28deg (0.33mm at pitch),
wedge-proof both directions. Bores 2.80: drop on the coupon base posts (CD 23.75).
"""
import numpy as np, os, sys, time
sys.path.insert(0, os.path.dirname(os.path.abspath(__file__)))
from shapely.geometry import Point, Polygon, MultiPolygon
from shapely.ops import unary_union
from shapely import affinity
import trimesh
from generator import cylinder
from generator_v13 import write_stl

CD=23.75; CLR=0.15
RH_S=2.0; CH_S=9.55-RH_S; CORE_S=6.3
SCULPT_CORE, SCULPT_LOBE = 14.3, 1.5
BORE=2.80; H=3.0
STEPS=700

def main_poly(g): return max(g.geoms,key=lambda p:p.area) if isinstance(g,MultiPolygon) else g

def sun_blank():
    parts=[Point(0,0).buffer(CORE_S,64)]
    for k in range(7):
        a=2*np.pi*k/7
        parts.append(Point(CH_S*np.cos(a),CH_S*np.sin(a)).buffer(RH_S,40))
    return unary_union(parts)

def build_pair():
    sb=sun_blank(); sd=sb.buffer(CLR,16).simplify(0.03)
    sweep=[]
    for phi in np.linspace(0,2*np.pi*12,STEPS,endpoint=False):
        psi=-(7/12)*phi
        w1=affinity.rotate(sd,np.degrees(phi),origin=(0,0))
        sweep.append(affinity.rotate(affinity.translate(w1,-CD,0),np.degrees(-psi),origin=(0,0)))
    sat=main_poly(Point(0,0).buffer(15.8,128).difference(unary_union(sweep)))
    sat=main_poly(sat.buffer(0.1,12).buffer(-0.1,12))
    sweep2=[]; td=sat.buffer(CLR,16).simplify(0.03)
    for psi in np.linspace(0,2*np.pi*7,STEPS,endpoint=False):
        phi=-(12/7)*psi
        w1=affinity.rotate(td,np.degrees(psi),origin=(0,0))
        sweep2.append(affinity.rotate(affinity.translate(w1,CD,0),np.degrees(-phi),origin=(0,0)))
    sun=main_poly(sb.difference(unary_union(sweep2)))
    sun=main_poly(sun.buffer(0.1,12).buffer(-0.1,12))
    # sculpt the month gear crests into tall rounded teeth (removal only)
    mask=[Point(0,0).buffer(SCULPT_CORE,96)]
    ch=15.80-SCULPT_LOBE
    for k in range(12):
        a=np.pi/12+2*np.pi*k/12
        mask.append(Point(ch*np.cos(a),ch*np.sin(a)).buffer(SCULPT_LOBE,40))
    sat=main_poly(sat.intersection(unary_union(mask)).buffer(0.08,12).buffer(-0.08,12))
    return sun, sat

def extrude(poly, h):
    p=Polygon(poly.simplify(0.02).exterior.coords,
              [list(Point(0,0).buffer(BORE,48).exterior.coords)])
    m=trimesh.creation.extrude_polygon(p,h)
    return [tuple(np.array(v) for v in m.vertices[f]) for f in m.faces]

if __name__=="__main__":
    os.chdir(os.path.dirname(os.path.abspath(__file__)))
    t0=time.time()
    sun,sat=build_pair()
    write_stl("121_ballmesh_sun_v16.stl", extrude(sun,H))
    tris = extrude(sat,H)
    tris += cylinder(10.5,0.0,2.5,H,9.0,seg=24)     # grip pin
    write_stl("121_ballmesh_month_v16.stl", tris)
    print(f"  built in {time.time()-t0:.0f}s — sun tip {max(np.hypot(*np.array(sun.exterior.xy))):.2f}, "
          f"month tip {max(np.hypot(*np.array(sat.exterior.xy))):.2f}, bores {BORE}")

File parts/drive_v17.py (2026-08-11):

#!/usr/bin/env python3
"""#149 DRIVE WHEEL v17 — the 24h wheel, with arms that reach 21h / 22h / 23h.

Ron: "I need the correct 24 hr wheel printed that can hit the 21,22,23 hours."

This is the part that has been blocking everything: without it there is nothing to
crank. The old 30_drive_v16 is only 15mm tall overall and was built for the 3.5mm
band spacing; the v17 stack at 6.5 pitch needs the 21h arm up at 24.7-25.5.

GEOMETRY, taken from the simulator, not invented:
  DDR 73.50   drive axis, from the board axis, along the strike line
  DBODY 29.2  body radius        -> reaches in to 44.30
  DTIP  32.76 arm tip orbit      -> reaches in to 40.74
Board tooth tip and satellite strike tip both stand at 41.86, so every arm engages
by 41.86 - 40.74 = 1.12mm — the drive window every clocking number is quoted against.
The body clears the board teeth by 2.44 and the satellites by 3.36.

ANGLES. The wheel turns once per day, so one hour is 15 deg. Each arm has to point
at the board (180 deg in the wheel frame) at its OWN hour, and the simulator draws
them at (180 - off) with off = 0/15/30/45 for 24h/23h/22h/21h. Verified: all four
land on world 180 at their hour.

ALTITUDES. Each arm hits a STRIKE TIP and must clear the MESH lamina 0.7mm below it:
  24h  board teeth      5.00 -  9.00
  23h  month strike    11.70 - 12.50   (month mesh ends 11.00)
  22h  feb strike      18.20 - 19.00   (feb mesh ends 17.50)
  21h  leap strike     24.70 - 25.50   (leap mesh ends 24.00)

WHY FOUR STACKED PIECES rather than one tall wheel. A single body would be a r29.2
cylinder 20.5mm tall — 55cm^3 — with four small tabs whose undersides are all
unsupported cantilevers. Split at each arm instead and every piece prints ARM DOWN
ON THE BED: no overhang anywhere, no supports, a quarter of the material. It is the
same idiom as the sun tower, and it is why the tower prints clean.

Each piece carries its arm at its own pre-rotated angle, so a plain square key
clocks all four correctly — exactly how the receivers handle their ALPHA. The key
is a sleeve (round bore on the fixture's r4.17 drive post, square outside), because
the drive post has to stay round: this wheel is the crank, it must turn.
"""
import numpy as np, os, sys
sys.path.insert(0, os.path.dirname(os.path.abspath(__file__)))
from shapely.geometry import Point, Polygon
from shapely.ops import unary_union
from shapely import affinity
from generator_v13 import write_stl
from weld import stack

DDR, DBODY, DTIP = 73.50, 29.20, 32.76
POST_R   = 4.17          # fixture drive post — round, design-at-bore (#136)
# The drive key CANNOT be the sun tower's K4. That key is 4.42 across, and the
# fixture's drive post is r4.17 = 8.34 diameter — bigger than the whole key. A
# sleeve has to wrap the post, so the square has to enclose it plus a wall:
#   8.34 bore + 2 x 1.58 wall = 11.50 across.
# (First cut used K4 and the bore simply ate the key, leaving four corner slivers —
# the weld gate caught it as "4 disconnected solids".)
SQ_HW    = 5.75          # drive square key half-width -> 11.50 across flats
HW_BASE  = 0.075         # arm half-angle at the body (rad), from the simulator
HW_TIP   = 0.030         # ...and at the tip: the arm tapers
ARMS = [("24h", 0.0,  5.00,  9.00, "board teeth"),
        ("23h", 15.0, 11.70, 12.50, "month strike tip"),
        ("22h", 30.0, 18.20, 19.00, "feb strike tip"),
        ("21h", 45.0, 24.70, 25.50, "leap strike tip")]
PIECE_TOP = {"24h": 11.70, "23h": 18.20, "22h": 24.70, "21h": 30.00}

def arm_poly(off_deg):
    """One tapered arm, body radius out to tip, centred on (180 - off)."""
    a = np.deg2rad(180.0 - off_deg)
    pts = [(DBODY*np.cos(a-HW_BASE), DBODY*np.sin(a-HW_BASE)),
           (DTIP *np.cos(a-HW_TIP),  DTIP *np.sin(a-HW_TIP)),
           (DTIP *np.cos(a+HW_TIP),  DTIP *np.sin(a+HW_TIP)),
           (DBODY*np.cos(a+HW_BASE), DBODY*np.sin(a+HW_BASE))]
    return Polygon(pts)

def piece(nm, off, z0, z1, top, no):
    """Body disc + its arm. The arm sits at the BOTTOM so the part prints arm-down
    on the bed — that is what makes the whole wheel support-free."""
    body = Point(0,0).buffer(DBODY, 192)
    key  = Polygon([(SQ_HW,SQ_HW),(-SQ_HW,SQ_HW),(-SQ_HW,-SQ_HW),(SQ_HW,-SQ_HW)])
    arm  = arm_poly(off)
    h = top - z0
    write_stl(no, stack([
        (0.0,      z1-z0, unary_union([body, arm]).difference(key)),   # arm band
        (z1-z0,    h,     body.difference(key)),                       # body above it
    ]))
    return h

def sleeve(no="169_drive_sleeve_revC_v17.stl", length=25.0):
    """Rev C (#167) — a RETRACTION of rev B, which is scrap.

    Rev B added a flange foot "standing on the fixture base at 2.5". The fixture
    has no bare base there: since r58 the drive post carries a COLLAR, r6.5 from
    the platform (4.0) up to exactly 5.0 — and the collar top IS the axial seat
    the #149 stack was designed around. The bottom piece's square bore (11.50
    across flats) cannot pass the collar's 13.0 diameter, so the stack seats at
    5.0 with no extra part at all. Rev B's r4.17 flange bore could not swallow
    the collar either, so the flange LANDED ON IT: stack at 7.5, every arm
    +2.5mm — 24h half-engaged on the board, 23h striking the empty gap between
    month tips and feb mesh, 22h/21h missing outright (Ron: "things are not
    lining up"). #159's premise — "the stack had no z-datum" — was wrong; the
    fixture always had one. Finding #159 is retracted to that extent and the
    June low-stack observation is REOPENED (whatever caused it, it was not a
    missing datum).

    Rev C is the honest sleeve: a straight keyed tube, bottom face seating on
    the collar top at 5.0 alongside the bottom piece, top flush with the 21h
    piece at 30.0. Round r4.17 bore (this wheel is the crank); square 11.50
    outside; length 25.0."""
    sq = Polygon([(SQ_HW,SQ_HW),(-SQ_HW,SQ_HW),(-SQ_HW,-SQ_HW),(SQ_HW,-SQ_HW)])
    bore = Point(0,0).buffer(POST_R, 64)
    wall = SQ_HW - POST_R
    assert wall > 1.0, f"sleeve wall only {wall:.2f}mm"
    write_stl(no, stack([(0.0, length, sq.difference(bore))]))
    return wall
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

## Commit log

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2026-07-25 v16c: flat-print sliders + T-pin peg inserts (finding 44 fix)
    New 31_sliders emission prints flat (no flip/sink/supports needed); cam
    peg is now a separate press-fit T-pin (37_peg_pins, prints head-down —
    the head is its own brim). Audit gains a grounded-geometry gate at
    compose time (sub-layer gaps tolerated) and a per-object first-layer
    extrusion check. Note: generator_v16.py was NOT in the design-office
    drop — repo generator still emits v16b; STLs are ahead of source.
    Known nit for the office: ID dots anchored at z1.80 over a z1.72 plate
    top (0.08 mm, sub-layer, prints fine).
    Claude-Session: https://claude.ai/code/session_014mT35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
    [31_sliders_v16.stl, 37_peg_pins_v16.stl]
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2026-07-25 v16d: vertical-socket sliders, drop-in pins, press-on crank module (findings 46–47)
    Generator updated (now in sync through part_37; 38_crank_module is a
    hand-authored field repair with no generator source). Bench events
    logged: finding-46 channel rail break (CA-repaired, rail reinforcement
    pending) and hub crank breakage (part 38 is the repair).
    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
    [31_sliders_v16.stl, 37_peg_pins_v16.stl, 38_crank_module_v16.stl]
2026-07-25 v16d full set: reinforced-rail wheel + refusal ring, vertical-socket sliders, drop-in pins, crank module (findings 44–47)
    30_drive re-emit: hub stops at z15 (crank module takes over — no more
    floating post), all components grounded. 31_sliders revised vs morning
    drop (same size, new content). 37/38 unchanged from 21db42a. Zip
    contained four STLs; generator_v16.py not included in this drop.
    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
    [30_drive_v16.stl, 31_sliders_v16.stl]
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2026-07-25 v16e r2: fan fix + degrees/radians emission repair (findings 48–49)
    Wheel: reworked channel architecture — outboard furniture (r29-32.4),
    bisector wedges, gate A14. r1's floating 21h outboard lip (degrees/
    radians bug, caught by the console mid-air gate) fixed at source;
    census verified: 22 mesh components, 1 physical cluster, zero floaters.
    Generator delivered and updated alongside. Bench findings 48 + the
    over-travel free-body note logged.
    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
    [30_drive_v16.stl]
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2026-07-25 bench fixture + ring carrier (parts 39–40) + camring first-layer pedestal (finding 50)
    Parts 39/40 verified grounded and printable. CAVEAT for the design
    office: the finding-50 pedestal annulus was emitted inside part_30
    (drive wheel) instead of the cam ring — sandbox emission shows an
    83.2mm wheel with a disconnected annulus floating 4.05mm above bed
    beyond the rim (bore 33.4 vs rim 32.8). The delivered r2 wheel STL
    predates the bug and stays correct; the cam ring STL is byte-identical
    to pre-finding-50 (no pedestal delivered anywhere). Gate A15 checks
    constants, not placement — passed regardless. Generator committed
    as-delivered for the record; do not re-emit part_30 from it.
    Co-Aut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
    [39_bench_fixture_v16.stl, 40_ring_carrier_v16.stl]
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2026-07-25 v16f: glue-free detent mount (finding 55) — ring indexes on board tick bumps, keyed clocking, pins +0.45
    32_camring: finding-50 pedestal now present, on a 0.55mm detent skirt
    (31 segments × 6 shells) that snaps over the board tick bumps; center
    clocking spider (post + 3 arms) requires ~24mm bridges at 0.55mm
    altitude — first bridging part of the project, flagged in readback.
    37_peg_pins: +0.45 (3.05mm total), verified. 30_drive updated from the
    files7 drop (unprinted revision, same size as r2, content differs).
    Generator from files8 (newest).
    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
    [30_drive_v16.stl, 32_camring_v16.stl, 37_peg_pins_v16.stl]
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2026-07-26 fixture r2: sun key, seating shoulder, jumper anchor (v1.3 station geometry)
    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
    [39_bench_fixture_v16.stl]
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2026-07-26 findings 60–64: jumper re-owned + open bores, square-key sun + fixture r4, receiver spacer
    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
    [39_bench_fixture_v16.stl, 41_jumper_v16.stl, 42_sun_v16.stl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]
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2026-07-26 jumper v10 + post sleeves (findings 74–75): mesh clearance stack + seating reach
    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
    [41_jumper_v16.stl]
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2026-07-27 findings 74–86: bearing sleeves, wire/printed detent studies, sun full column, drive-train corrections
    Swapped: 45 (wire jumper holder, newest), 46 (wedge set), 47 (detent arm
    r2), 48 (drive peg — WITHDRAWN per finding 86, archived), 02_program_wheel
    (current source — 31 tick bumps + tall pos-1 witness verified in census;
    stl_v13 archive copy untouched). 44 already current. NOT landed despite
    the manifest: 42_sun r2 full column, current generator — awaiting drop.
    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
    [02_program_wheel.stl, 45_wire_jumper_holder_v16.stl, 46_wedge_set_v16.stl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]
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2026-07-27 detent set: basin fixture r5, star ring, arm r3 (findings 82–87)
    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
    [49_fixture_r5_v16.stl, 50_detent_star_v16.stl]
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2026-07-28 finding 100: qc_sweep_central path resolution — gate must clear from repo root
    Shipped load() searched only stl_v13/ and ./; from repo root it found zero
    of the six parts, printed a vacuous CLEAN over an empty set, then crashed
    (NoneType, exit 1). Geometry independently verified clean (unmodified
    script in a scratch dir where paths resolve: all six load, CLEAN, exit 0).
    Fix: load path now includes parts/stl/ and parts/stl_v13/. Re-run from
    repo root: genuine CLEAN, exit 0. Doctrine #96 upheld — the committed
    gate is the gate that clears the plate.
    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
    [02e_board_bigbore_v16.stl, 33_receiver_month_r2_v16.stl, 49_fixture_r54_v16.stl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]
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2026-07-28 plate-17b fixture-only reprint staged: r58 (post rooted, finding 101 fix)
    Both gates green incl. new [4] base-connectivity (program post rooted
    bed->9). Single-part fixture plate, no supports, 120 layers, 210C/55C,
    retraction 1.6, z-hop 0.4. enable_prime_tower set but Bambu emits no
    tower for single-filament (no tool changes) — effective anti-string is
    retraction+temp+z-hop. Board/star/bridge from plate-17 unaffected, not
    reprinted. NOT started — awaiting Ron's go.
    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
    [49_fixture_r57_v16.stl, 49_fixture_r58_v16.stl]
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2026-07-28 board 02f + engine clearance sweep (finding #102)
    Engine sweep (parts/engine_sweep.py, disc-about-fixed-pivot, frame self-
    checked vs sun<->month mesh): board 02e lets the tall day-1 peg (+0.8mm)
    and station dots M/F (+0.2mm) skim the month satellite mesh lamina despite
    the finding-63 spacer. Board 02f removes all 31 pegs + 3 dots -> sweep
    CLEAR; rim/bore/post+D-key unchanged so the flag-free press-fit is intact.
    Sun tower confirmed configured. Both boards watertight. plate-18 ready.
    [02f_board_v16.stl]
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2026-07-29 finding #107: restore multi-level sun + compact receivers (sim heights) — fixes finger-sun collision + mesh jam
    [02h_board_v16.stl, 33_receiver_month_r2_v16.stl, 34_receiver_feb_v16.stl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]
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2026-07-29 finding #108: re-tune sun (Ron bench) — taller slim cores + mesh backlash + XY comp
    [42_sun_v16.stl]
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2026-07-29 finding #113: satellite-post tolerance-ladder coupon (radii 2.50-2.65) + quiet plate-22
    Ron's photo: receiver has real slop on its round pivot post -> gear cocks/drifts,
    mesh alternately jams and skips. FDM makes the exact fit unguessable, so print a
    coupon of 4 stub posts (board 02h seat shoulder + 3mm bearing, only radius varies),
    drop the existing receiver on each, lock the snug-but-free radius into 02h POST_R.
    plate-22 carries xy_contour_compensation -0.06 (matches the board) + quiet overrides.
    [113_post_tolerance_coupon_v16.stl]
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2026-07-29 finding #113 lock-in: board 02h POST_R 2.65 + fixture r59 + solid-finger receiver; REQUEST plate-23 (silent)
    r2.65 won the plate-22 tolerance ladder (snug, no wobble, still spins/reverses).
    Locked into part_02h_board_v16 POST_R; regenerated board/fixture/receiver STLs,
    all watertight; post top z12.5 still clears the feb band by 0.5mm. plate-23 carries
    xy_contour_compensation -0.06 (mandatory: the value the fit was chosen under) + quiet
    overrides. Reuse the 3-piece sun. Board reprint requested silent in print-log.
    [02h_board_v16.stl, 33_receiver_month_compact_v16.stl, 49_fixture_r59_v16.stl]
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2026-07-30 findings #114+#115: central sleeve ladder + involute mesh coupon; REQUEST plate-24 (silent, one plate)
    #114 sleeve ladder (tube bore 4.27/4.22/4.17 on r4.15 post) to kill the board-post
    play still binding after the #113 gear-post fix. #115 involute mesh coupon: 7t
    profile-shifted involute sun + 12t involute sat @ CD 23.75, tips capped to the
    current envelope (9.55/15.8), roots kept (7.4/13.4). Mesh proof: 0.00mm2 tooth
    overlap through a full roll vs 0.42mm2 for the trapezoid; sat-tip clears sun valley
    0.55mm. Both hand-tests on one quiet plate, no supports, xy-comp -0.06.
    [114_central_sleeve_id17_v16.stl, 114_central_sleeve_id22_v16.stl, 114_central_sleeve_id27_v16.stl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]
2026-07-30 #115 matched: mesh coupon uses REAL involute parts at engine heights (multi-level sun section + compact receiver)
    Replaces the flat equal-height stand-ins. Sun = full involute band (z0-1.5) + slim
    core (z1.5-4.5); receiver = involute mesh lamina + solid fingers. Both seat at z3.5
    so the mesh lamina lands on the sun full band coplanar (3.5-5.0), exactly like the
    assembly; fingers clear the slim core 0.75mm. plate-24 updated to the matched parts.
    [115_meshtest_receiver_inv_v16.stl, 115_meshtest_sun_piece_inv_v16.stl]
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2026-07-30 #116 mesh backlash ladder: drop the profile shift (fat sun tooth was binding) + ladder backlash
    Coupon bound because the +0.4 shift made the sun tooth 4.28mm at pitch (fatter than
    nominal 3.93) -> no room for FDM swell. Clean stub involute (x=0) drops it to ~3.0mm
    and still meshes 0.00mm2 in sim. Ladder 3 pairs at backlash 0.5/0.9/1.3, bores opened
    to 2.80 to isolate the mesh. Also: sleeve id17 (bore 4.17) won the central bearing.
    [116_meshladder_base_v16.stl, 116_meshladder_rec_bl05_v16.stl, 116_meshladder_rec_bl09_v16.stl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]
2026-07-30 #117: coupon finger/sun vertical-clearance fix; REQUEST plate-26 (silent)
    Sun full band shortened (top 0.5mm below the finger bottom, was zero margin) and the
    finger's unsupported overhang raised (underside 1.2mm above the band) so print droop
    lands in air, not on the sun tooth. Sun also drops the #116 profile shift. Same fix
    pattern to be carried into the real multi-level sun + receivers with the plate-25
    backlash winner.
    [115_meshtest_receiver_inv_v16.stl, 115_meshtest_sun_piece_inv_v16.stl]
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2026-07-31 #121: keyed ball sun (square bore hw2.25, 4mm) for the board+fixture rig; REQUEST plate-28 (silent)
    [121_ballmesh_sun_keyed_v16.stl]
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2026-07-31 #124: socket seat clearance halved (ball touches both flanks seated, per patent) on grown geometry; REQUEST plate-31 (silent)
    [124_ballsun_keyed_tight_v16.stl, 124_month_b270_tight_v16.stl]
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2026-08-01 #137: tighter board wheel — id17 bore baked in, real press fit restored, bearing lengthened; REQUEST plate-41 (silent)
    [49_fixture_r61_v16.stl, 50e_star_hub_v16.stl]
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2026-08-01 #138: Ron's winning cross-pair locked — sun re-carved to his month gear + clocked; shrink-is-backlash law; REQUEST plate-42 (silent)
    [138_sun_ronpair_clocked_v16.stl]
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2026-08-01 #141 v17 rev B: fix engine/carrier assembly collision, add whole-stack gates
    plate-43 rev A would not assemble. The receivers' 3mm anti-tilt hub boss made
    them 6mm tall, but the band gap only holds a 3mm satellite, so month and feb
    drove 2.8mm through the carrier arm crossing above them. Each plate's own gates
    passed - the collision was BETWEEN plates.
    - boss removed from month/feb (3.0mm bearing, as Ron's bench pair already runs);
    leap keeps 1.2mm, it has open sky above
    - sun tower piece 4.5 -> 5.0mm: the piece height IS the band pitch, and 5.0 is
    what pays for 0.20 clearance + 1.30 arm plate + 0.50 pivot pad + 3.00 satellite
    - carrier arm pad moved into the budget: satellites now land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
    [140_sun_tower_piece_v17.stl, 141_receiver_month_v17.stl, 142_receiver_feb_v17.stl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]
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2026-08-01 #142 datum chain: fixture key too short, shim fouled the board, board bore halved
    Ron, from the hardware: "because the satellite gear sits elevated the sun gear is
    low." Chasing that down the stack found three faults, none of which anything above
    the board could see. The satellite's altitude hangs off the BOARD (its pivot pad);
    the sun's hangs off the FIXTURE (the round post's top face at z8.5). Nothing was
    checking that the two chains arrive at the same altitude.
    1. FIXTURE KEY TOO SHORT. The sun tower now reaches z24.5 but the K4 key stopped at
    18.0 - the top TWO sun pieces had nothing to key against. Free to rotate does not
    merely loosen the mesh, it destroys the #134 clocking the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
    [144_board_02j_v17.stl, 147_sun_spacer_1mm_v17.stl, 148_fixture_r62_v17.stl]
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2026-08-01 #143 board day numbers 1-31 (two-colour, both faces) + two-filament compose support
    Ron: white date numbers on the board so he can see how to set the mechanism.
    Geometry (board_numbers_v17.py -> 149_board_02k_numbered + 150_daynums_white):
    - date convention taken from the simulator's underside pin crown, not invented:
    date = (steps mod 31)+1, so date d sits at board-frame 90 - (d-1)*11.613 with
    digits' up radially outward; the number at the index (world 90) is the date.
    Witness notch outboard of date 1 confirms the ring's clocking at a glance.
    - numbers cut into BOTH faces (0.8mm, 2.4mm core). The three satellites are
    carried BY the board, so their shadow is fixed in board frame and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
    [149_board_02k_numbered_v17.stl, 150_board_daynums_white_v17.stl]
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2026-08-01 #144: the bed was wrong — 200x200x100 vs the P1S's real 256x256x256, plus a placement gate
    Ron's Swoopy poop chute (182mm tall) surfaced a bug affecting every plate composed
    so far. The flattened canonical config claims printable_area 200x200 and
    printable_height 100 for a P1S. Its actual build volume is 256x256x256. Meanwhile
    compose_plate's own BED constant was hard-coded 256, so the two halves of the
    composer disagreed: 'center' placed parts at 128,128 inside a bed the slicer
    believed was 200 wide.
    That is why plate-41 and plate-43 both had to be reflowed by hand at the printer.
    It was never a bad coordinate from the design office. It also silently capped the
    machine at 100mm of Z, and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
    [swoopy_poop_chute.stl]
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2026-08-02 #145 satellite labels: month names + 1-12, derived from the calendar engine
    Ron: white markings on the satellites so he can see how to set them.
    WHICH TOOTH IS WHICH MONTH is measured, not assumed. At 23:00 on date 30 the 23h
    arm sweeps the month wheel and whichever tooth is on the strike line IS that
    month's tooth - true for all twelve, not just the five that fire. Single-valued
    over 14 simulated years. The long teeth come out as five consecutive positions
    whose months are exactly February plus the four 30-day ones, which is the check
    that says the mapping is right and one Ron can make on the printed part.
    An algebraic shortcut got this wrong first: one month is 19 satellite teeth, but
    th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
    [151_receiver_month_lab_v17.stl, 152_receiver_feb_lab_v17.stl, 153_receiver_leap_lab_v17.stl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]
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2026-08-02 #146 carrier arm: pivot pad overhung its own press-fit bore (Ron, bench)
    'Is the peg supposed to block part of the hole?' No.
    Measured from the emitted file: a full-circle r3.50 pivot pad at a 4.81mm station
    spacing, against a r2.60 bore, covers 1.29mm of the 5.20mm bore mouth across 120
    degrees of its rim. 6.10mm of feature in 4.81mm of space.
    It bites twice. The lip prints unsupported over the hole and droops exactly where
    the satellite bears, and a post that comes out even slightly long fouls the lip so
    the arm never fully seats.
    Pad is now clipped clear of the bore with 0.30 clearance, retaining 296 of 360
    degrees of thrust contact at the satellite's bore edge - ample for a hand-crank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
    [145_carrier_feb_v17.stl, 146_carrier_leap_v17.stl]
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2026-08-03 #147 + #148 + #149: 6.5 band pitch, per-satellite strike clocking, and the drive wheel
    #147 (Ron, bench: "the small posts do not have a tall enough post to grab the last
    post"). Band pitch 5.0 -> 6.5. The arm plate thickness IS the entire grip the arm has
    on its post, because the post must stop under the satellite above; 1.30mm on a 2.70
    post would not hold. Budget: 3.00 satellite + 0.20 clearance + 2.80 plate + 0.50 pad.
    Bands move 9.5/14.5/19.5 -> 9.5/16.0/22.5; sun piece 5.0 -> 6.50 (taken in the piece,
    not as 0.5mm shims, which print at 2.5 layers and walk the lamina off its band).
    157_fixture_r63 keys to 29.5 and carries the drive post to 26.0; it REPLACES r62.
    #148 (Ron, bench: "1 is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
    [140_sun_tower_piece_v17.stl, 141_receiver_month_v17.stl, 142_receiver_feb_v17.stl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]
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2026-08-08 #152 stepped post + #153 text legibility; plates 49/50 for the engine reprint
    #152 STEPPED POST (Ron's call). The arm's problem was never grip LENGTH — it was that
    the arm seated on the ROTATING satellite's top face across a 0.20 running clearance, so
    it had no datum at all. That is the float Ron felt: "the small posts do not have a tall
    enough post to grab the last post." Adding length would not have fixed it; nothing was
    holding height. The post now runs full 5.40 through the satellite that rides it, then a
    0.60mm SHOULDER, then a 4.20 spigot the arm bottoms against — a stationary face on the
    post sets the arm's height and squareness instead of a gear that is turning under it.
    grip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
    [144_board_02j_v17.stl, 145_carrier_feb_v17.stl, 146_carrier_leap_v17.stl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]
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2026-08-09 #156 detent: full-pitch V star + wire jumper — rest IS the station
    Ron: "there is plenty of backlash for each day... we want it to eliminate that
    backlash so it stops in the same place each day." Correct, and stricter than
    comfort: rest slop spends from the same 1.12mm window as mesh lash, and the #155
    July restoration margin assumes the board starts each evening centred.
    WHY NOT THE BOARD'S OWN TEETH (measured): a nose wedged in the involute valleys
    centres perfectly at rest but the tooth tips carry a wide flat land - a ZERO-SLOPE
    PLATEAU from 3.4 to 7.4 deg at EVERY nose radius tried (0.5..4.0). The 4.63deg
    July release sits dead centre of it: the board would strand mid-tooth with no
    re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
    [144_board_02j_v17.stl, 149_board_02k_numbered_v17.stl, 163_detent_holder_v17.stl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]
2026-08-09 #156 rev B + #157: ALL-PRINTED detent (Ron's law: no wire), second bridge at 16 pitches
    NO WIRE ANYWHERE IN THE BUILD - new standing constraint from Ron; the music-wire
    jumper of c415ada is retired before ever being printed. Replacement: a flat 2.0mm
    PLUG-IN PLA LEAF SPRING (165, three stiffnesses: leaf 2.6/3.0/3.4 -> 0.33/0.51/
    0.74 N/mm). PLA creep answered three ways: resting strain ~0.1% (preload only
    0.35mm on a 40mm leaf - creep-negligible; the ~0.4% escape strain is transient),
    the spring is a 5-minute consumable that presses into an open-top pocket, and the
    three stiffnesses replace the wire's slide-to-tune.
    #157 SECOND BRIDGE (Ron's idea, with one correction the geometry demanded).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
    [163_detent_holder_v17.stl, 164_detent_star_v17.stl, 165_detent_spring_firm_v17.stl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]
2026-08-09 #157b: holder registration — position from the fixture, not from tape
    Ron: "can you position the 2nd detent properly so it has the desired effect?"
    Verified and closed, in three parts.
    1. ANGULAR POSITION PROVEN (measured off the emitted star): with the north
    bridge at 16 whole pitches the combined energy well is exactly 2.00x a single
    bridge; at a literal 180.00 it degrades to 1.28x with the rest positions pulled
    off-station (figure: detent_positioning.png). The 31-odd anti-phase trap is
    real and measured, not narrated.
    2. HONEST CORRECTION: the radial-load claim in 7c932d9 said "cancel to 1%".
    Wrong: the residual is |2cos(185.81/2)| = 10% of one spring's force, ~0.09 N
    with a med pair.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
    [163_detent_holder_v17.stl, 166_detent_holder_north_v17.stl]
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2026-08-09 #159: the drive stack had no axial seat — flanged sleeve rev B
    Ron, bench: "I think the 23 hr goes slightly beneath the satellite." Correct, and
    the cause is a DESIGN HOLE in #149, not a print error: the stack had no z-datum.
    Nothing held the sleeve at height - it slid down the post until it sat on the
    fixture base at 2.5, dropping every arm 2.5mm. The 23h arm ran at ~9.2-10.0,
    under the month strike tips (11.70-12.50) and into the mesh lamina zone. The 24h
    arm's tall 4mm band kept the daily train alive - which is why the crank video
    looked healthy while the strike train was low. An altitude fault that hides
    behind a working daily step is exactly the kind of thing only the bench sees.
    Fix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
    [162_drive_sleeve_v17.stl]
2026-08-09 #160: bidirectionality ASSERTED, not named — reverse-sweep gate; 'sawtooth' purged
    Ron: "the type of detent you built only works in one direction which defeats the
    reverse." The geometry was symmetric all along — but the WORD was wrong and the
    GATE was one-eyed. 'Sawtooth' means ratchet; what is cut is a symmetric TRIANGLE
    wave (both flanks of every V equal), and the spring is a radial jumper, not a
    tangential pawl, which is the whole difference between a detent and a ratchet.
    The gate had only ever swept the star FORWARD. It now sweeps the same bearing
    BACKWARD and demands the mirror. Measured off the emitted STL: forward and
    reverse lift curves identical to 0.1 MICRON over the full pi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
    [detent_accept_v17.py, detent_v17.py]
2026-08-09 #161: spring rev C — Ron's elbow review, and the fault behind it
    Ron, on the render: "that detent arm looks like it will snap at the elbow."
    Operational stress at the elbow is ~1 MPa (it is near the free end), but his
    instinct holds for ASSEMBLY loads, which lever the elbow directly, and a sharp
    interior corner in brittle PLA is a pre-written crack. Rev C: finger tapered
    5.5 -> 3.6 (+53% root section) and r2.5 fillets on every interior corner via a
    closing buffer (convex corners and the 8.3 press tab survive the round trip).
    The fillet work exposed two more faults:
    1. THE SPRING COULD NOT BE INSTALLED AT ALL - the pocket's 2mm west wall blocked
    the leaf; the tab would have jammed 3.3mm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
    [163_detent_holder_v17.stl, 165_detent_spring_firm_v17.stl, 165_detent_spring_med_v17.stl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]
2026-08-09 #162: BRIDGE spring — held on both ends (Ron's law of free ends)
    Ron: "we learned this lesson already - this design needs to be a bridge type held
    on both ends." The ledger agrees: #147 (cantilevered post grip), axis-06 (lone
    unsupported column), #159 (unseated sleeve) - every free end in this project has
    eventually failed, and the cantilever jumper would have been next.
    The spring is now a beam FIXED AT BOTH ENDS, nose at mid-span: tab | leaf |
    centre T (finger + r1.4 nose) | leaf | tab, one flat 2.0mm piece. Fixed-fixed is
    16x stiffer per length (k = 192EI/L^3) so the span is 70mm with a thinner leaf
    (widths 1.2/1.4/1.6 -> k 0.39/0.61/0.92 N/mm, escape 0.66/1.04/1.56 N). No free
    end to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
    [163_detent_holder_v17.stl, 165_detent_spring_firm_v17.stl, 165_detent_spring_med_v17.stl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]
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
